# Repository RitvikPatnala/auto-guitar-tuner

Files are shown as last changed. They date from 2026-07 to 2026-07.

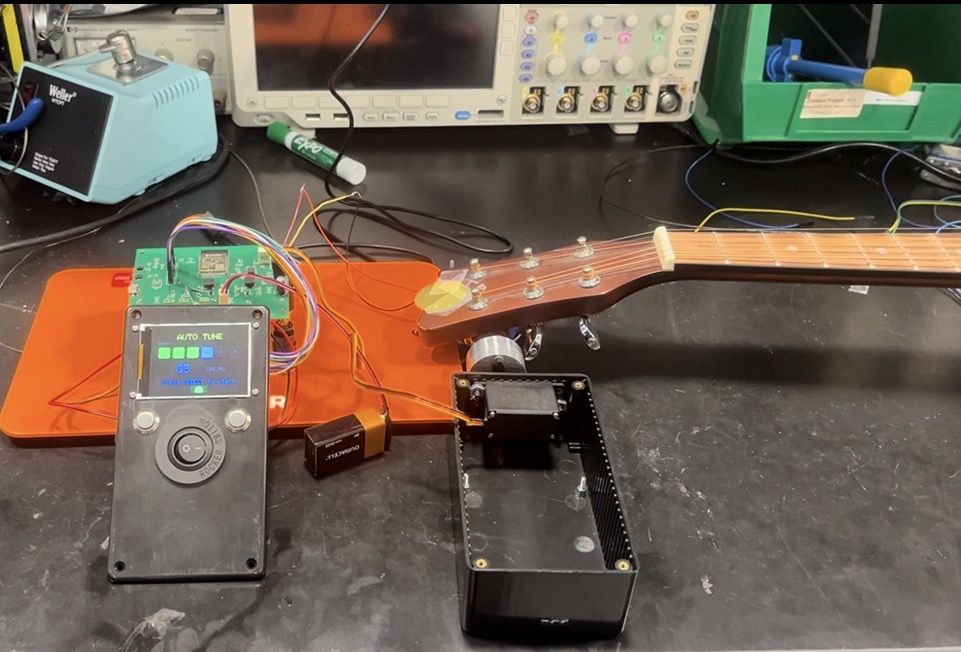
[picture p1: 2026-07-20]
docs/Guitar Tuner Demo.jpg

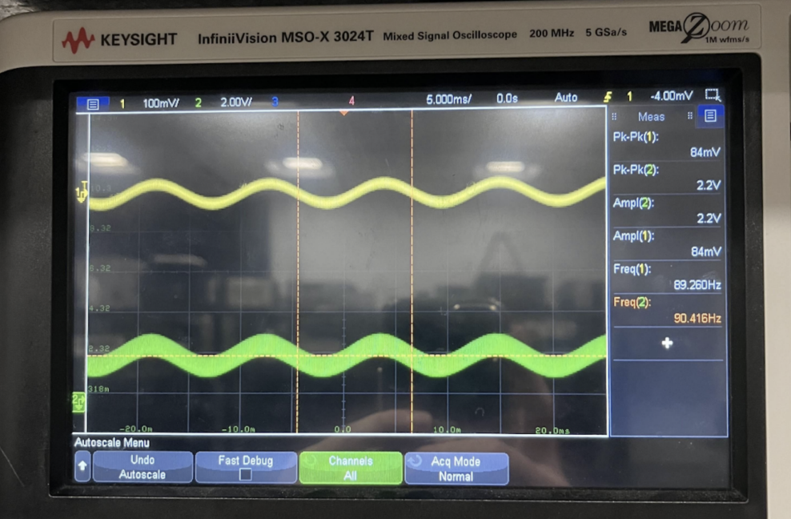
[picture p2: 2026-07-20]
docs/Amplified Output.png

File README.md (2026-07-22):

# Auto Guitar Tuner

A handheld device that detects a guitar string's pitch and physically rotates the tuning peg until the string is in tune. Built around a custom ESP32-S3 PCB designed from schematic capture to routed layout, with real-time pitch detection firmware and closed-loop servo control. Tunes to within ±12 cents across all six strings and multiple tuning standards (Standard, Eb, Drop D, Open G).

Screenshot 2026-07-20 at 3 30 26 PM

## How it works?

1. A piezo vibration sensor mounted on the guitar picks up string vibrations (immune to ambient room noise, unlike a microphone).
2. An LM386 amplifier stage (gain ≈ 50) with a 1.6 kHz RC anti-aliasing filter conditions the signal for the ESP32-S3's ADC (8192 Hz, 12-bit).
3. Firmware detects the fundamental frequency using time-domain autocorrelation and computes the error from the target pitch in cents.
4. A PID controller drives an HS-318 servo attached to the tuning peg, making small angular corrections until the string is in tune — with safety interlocks (rotation limits, stall           detection, voicing threshold) to protect the guitar.
5. A TFT LCD (SPI) and two-button interface let the user select strings and tuning modes via an FSM-driven UI.

## Why Autocorrelation instaead of FFT?

The most interesting design decision in the project. Guitar strings produce strong harmonics — the 2nd harmonic often carries more energy than the fundamental, so naive FFT peak-picking frequently reports the octave above the true pitch. Time-domain autocorrelation measures the signal's self-similarity across lag values, which naturally locks onto the fundamental period. It was also faster on the ESP32-S3:

| Approach | Latency |
|---|---|
| Autocorrelation | ~22 ms |
| FFT + peak detection | ~48 ms |

The pipeline: Hann window → autocorrelation over the guitar's lag range (73–330 Hz) → normalization → zero-crossing peak detection → parabolic sub-sample interpolation for resolution beyond the lag grid. The ~22 ms loop lets the tuner track pitch continuously while the motor turns, so the user doesn't need to re-pluck after every adjustment.

## Hardware Design

- Power: dual AP62150 buck converters (9V battery → 5V and 3.3V rails). Chosen over LDOs after a dissipation analysis — a stalled servo draws 800 mA, which would burn 3.2 W in an LDO vs ~90% buck efficiency.
- Custom PCB: designed in KiCAD (schematic → layout), simulated in LTSpice; noise mitigated with ground partitioning, supply decoupling, and the RC input filter.

Screenshot 2026-07-21 at 8 55 34 PM

Screenshot 2026-07-21 at 8 56 06 PM

- Motor: HS-318 analog servo, selected over a stepper for closed-loop position feedback and full torque at low speed. Torque analysis: 0.25 kg·cm required at the peg vs 3.7 kg·cm available.

## Verification Highlights

| Subsystem | Result |
|---|---|
| Power rails | 3.353 V / 4.995 V measured (±1% of nominal) |
| Audio chain | Gain of ~52 measured (target 50); piezo signal 84 mV |
| Pitch detection | ±12 cents final tuning accuracy, ~22 ms latency |
| Control | Autonomous tuning verified on all 6 strings + alternate tunings |

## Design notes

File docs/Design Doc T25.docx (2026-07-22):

# Outline

Tim Ritvik Daniel

1. Introduction
  - Problem and Solution: Reuse, edit original One to two paragraphs explaining the context of the problem to be solved by your project, including any relevant references to justify the existence and/or importance of the problem (i.e., the need or want for a solution). Justify the novelty of your solution or explain the expected improvements of your solution over previous results.
  - Visual Aid A pictorial representation of your project that puts your solution in context. Not necessarily restricted to your design. Include other external systems relevant to your project (e.g. if your solution connects to a phone via Bluetooth, draw a dotted line between your device and the phone). Note that this is not a block diagram and should explain how the solution is used, not a breakdown of inner components.
  - High-level requirements list: Rework Original A list of three to four objective characteristics that this project must exhibit in order to solve the problem. These should be selected such that if any of these requirements were not met, the project would fail to solve the problem. Avoid vague requirements that can be interpreted a number of ways (e.g. "The radio subsystem should work reliably."). Each high-level requirement must be stated in complete sentences and displayed as a bulleted list.
2. Design
  - Block Diagram: Mostly done, maybe needs rework? A general block diagram of the design of your solution. Each block should be as modular as possible and represent a subsystem of your design. In other words, they can be implemented independently and re-assembled later. The block diagram should be accompanied by a brief (1 paragraph) description of the critical subsystems and what they do.
  - Physical Design (if applicable): A physical diagram of the project indicating things such as mechanical dimensions or placement of sensors and actuators. The physical diagram should also be accompanied by a brief one paragraph description.
  - [Subsystem X] All subsystems needs requirements and verification For each subsystem in your block diagram, you should include a highly detailed and quantitative block description. Each description must include a statement indicating how the block contributes to the overall design dictated by the high-level requirements. Any and all design decisions must be clearly justified. Any interfaces with other blocks must be defined clearly and quantitatively. Include any relevant supporting figures and data in order to clearly illustrate and justify the design. Typically a well justified block design will include some or all of the following items: Circuit schematics, simulations, calculations, measurements, flow charts, mechanical diagrams (e.g. CAD drawings, only necessary for mechanical components). You must include a Requirements and Verifications table. Please see the R&V page (https://courses.grainger.illinois.edu/ece445/guidelines/requirements-and-verification.asp) for guidance on writing requirements and verification procedures.
  - Motor Subsystem ...
  - Audio Subsystem
  - Power Subsystem
  - Microcontroller Subsystem
  - USB-C Subsystem
  - LCD Subsystem ...
  - Tolerance Analysis: Through discussions with your TA, identify the block or interface critical to the success of your project that poses the most challenging requirement. Analyze it mathematically and show that it can be feasibly implemented and meet its requirements. See the Tolerance Analysis guide (https://courses.grainger.illinois.edu/ece445/documents/tolerance-analysis-guide.pdf) for further guidance.
  - Include any relevant supporting figures and data in order to clearly illustrate and justify the design. Typically a well justified block design will include some or all of the following items: Circuit schematics, simulations, calculations, measurements, flow charts, mechanical diagrams (e.g. CAD drawings, only necessary for mechanical components). You must include a Requirements and Verifications table. Please see the R&V page (https://courses.grainger.illinois.edu/ece445/guidelines/requirements-and-verification.asp) for guidance on writing requirements and verification procedures.
  - [Subsystem Y] ...
  - [Subsystem Z] ...
  - Tolerance Analysis: Through discussions with your TA, identify the block or interface critical to the success of your project that poses the most challenging requirement. Analyze it mathematically and show that it can be feasibly implemented and meet its requirements. See the Tolerance Analysis guide (https://courses.grainger.illinois.edu/ece445/documents/tolerance-analysis-guide.pdf) for further guidance.
3. Cost and Schedule
  - Cost Analysis: Include a cost analysis of the project by following the outline below. Include a list of any non-standard parts, lab equipment, shop services, etc., which will be needed with an estimated cost for each.
    i. Labor: (For each partner in the project) Assume a reasonable salary ($/hour) x 2.5 x hours to complete = TOTAL Then total labor for all partners. It's a good idea to do some research into what a graduate from ECE at Illinois might typically make.
    ii. Parts: Include a table listing all parts (description, manufacturer, part #, quantity and cost) and quoted machine shop labor hours that will be needed to complete the project.
    iii. Sum of costs into a grand total
  - Schedule: Include a time-table showing when each step in the expected sequence of design and construction work will be completed (general, by week), and how the tasks will be shared between the team members. (i.e. Select architecture, Design this, Design that, Buy parts, Assemble this, Assemble that, Prepare mock-up, Integrate prototype, Refine prototype, Test integrated system).
4. Discussion of Ethics and Safety:
  - Expand upon the ethical and safety issues raised in your proposal to ensure they are comprehensive. Add any ethical and safety concerns that arose since your proposal.
  - Document procedures to mitigate the safety concerns of your project. For example, include a lab safety document for batteries, human/animal interfaces, aerial devices, high-power, chemicals, etc. Justify that your design decisions sufficiently protect both users and developers from unsafe conditions caused by your project. Projects dealing with flying vehicles, high voltage, or other high risk factors, will be required to produce a Safety Manual and demonstrate compliance with the safety manual at the time of demo.
5. Citations:  Any material obtained from websites, books, journal articles, or other sources not originally generated by the project team must be appropriately attributed with properly cited sources in a standardized style such as IEEE, ACM, APA, or MLA.

# Design Doc

# Auto-Guitar Tuner Design Document

Daniel Cho, Ritvik Patnala, Timothy Park
Team 25 - TA: Eric Tang

Abstract

This document provides a comprehensive description of the Auto-Guitar Tuner, a handheld device that automates guitar tuning by integrating pitch detection, microcontroller-based control, and motorized peg adjustment. It outlines the system architecture, physical and functional designs, subsystem requirements and verifications, software flow, tolerance analyses, cost considerations, and safety protocols. The tuner is designed to operate as a standalone portable device compatible with standard six-string guitars.

1. Introduction 4

1.1 - Problem and Solution 4

1.2 - Visual Aid 4

1.3 - High-level requirements list 4

2. Design 5

2.1 - Block Diagram 5

2.2 - Physical Design 6

2.3 - Subsystems 7

2.4 - Tolerance Analysis 21

3. Cost and Schedule 22

3.1 - Cost Analysis 22

3.2 - Schedule 24

4. Discussion of Ethics and Safety 26

6. Citations 30

# 1. Introduction

## 1.1 - Problem and Solution

Problem: When playing guitar, being in tune is essential. When strings are not properly tuned to their correct pitches, the notes played can clash with each other, causing what listeners perceive as being "off" or "out of tune." Accurately tuning a guitar is a challenge for both beginners and experienced players. Traditional tuners require the musician to manually turn tuning pegs while reading pitch information, which can be inconsistent and time-consuming. An automatic solution that can both detect pitch and physically adjust the tuning peg would reduce errors, speed up tuning, and improve usability in practice and performance settings.

Solution: We propose a handheld automatic guitar tuner integrating pitch detection and motorized peg adjustment into one device. The system will capture string vibrations, process them using a microcontroller to identify the current pitch, and automatically rotate the tuning peg with a small motor until the string is in tune. Since the handheld device tunes one string at a time, it can be used on different guitars without worrying about the various spacing between pegs and strings. A compact LED screen will display the detected pitch and tuning status, while four buttons (Power, String Select, Mode, Start) provide simple user control. The String Select button allows users to cycle through the six guitar strings. Each press moves the selection to the next string in order: low E, A, D, G, B, high E, then back to low E again. This circular navigation lets users easily choose which string to tune without confusion or the need for multiple buttons. The Mode button lets users toggle between preset tuning standards (Standard, Drop D, Open G, etc) to accommodate various playing styles and preferences. The design will run on a rechargeable battery, with all subsystems integrated into a custom PCB for portability and reliability.

## 1.2 - Visual Aid

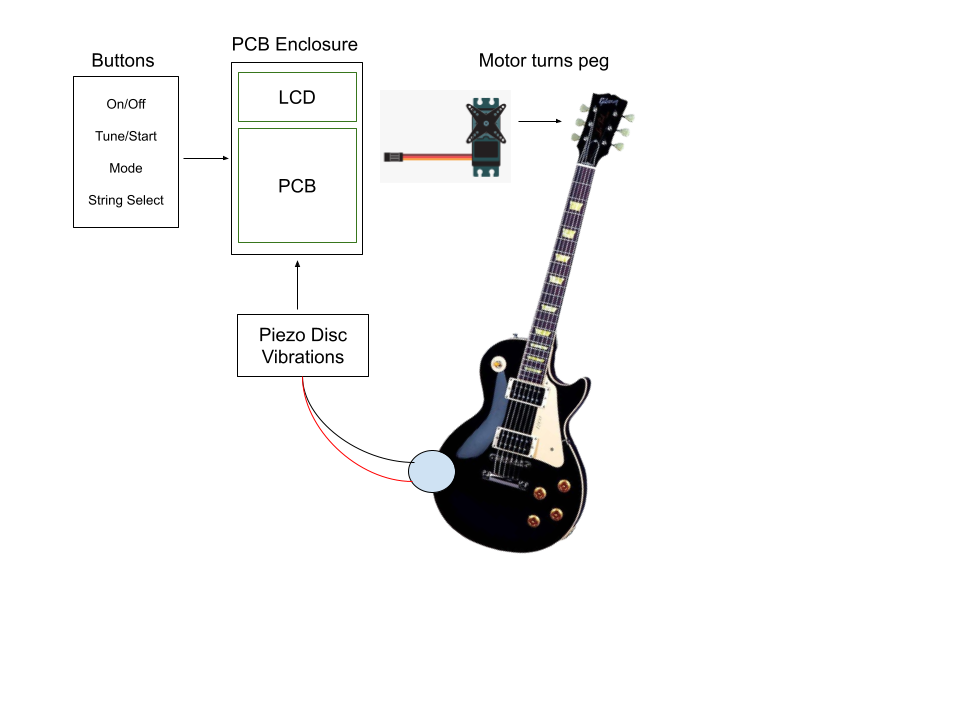
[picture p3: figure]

## 1.3 - High-level requirements list

# 2. Design

## 2.1 - Block Diagram

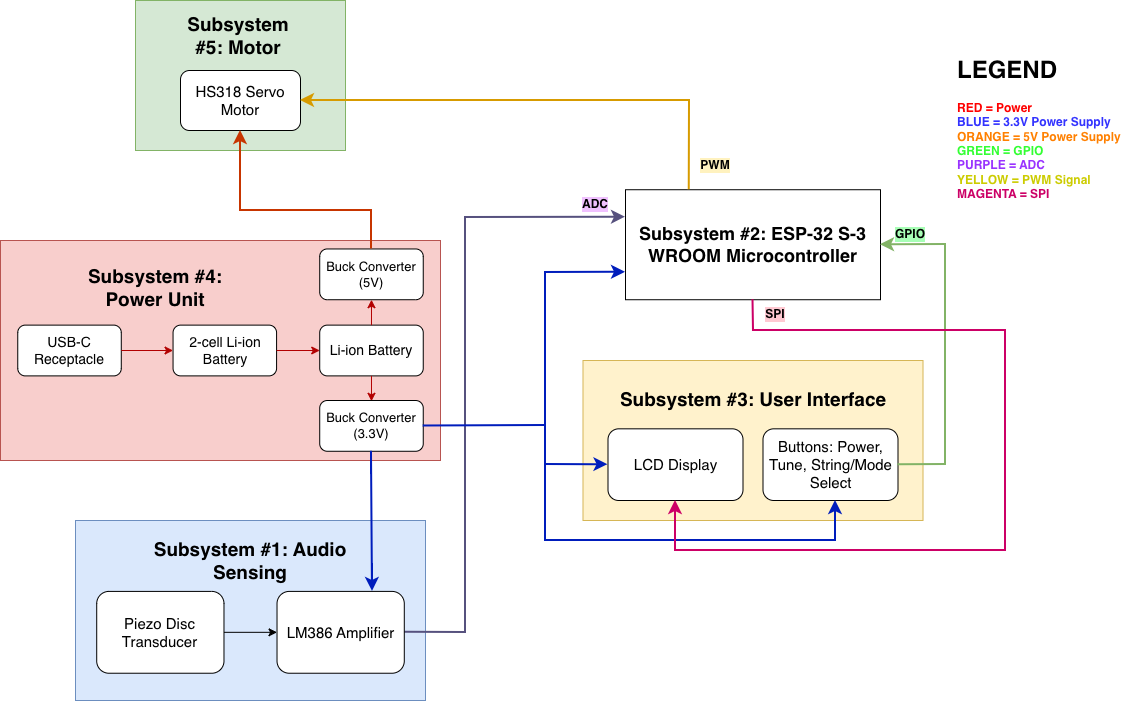
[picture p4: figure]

Figure 1. Image of the block diagram

The system consists of five main subsystems: Power Management, Microcontroller, Audio Sensing, User Interface, and Motor. The ESP32 microcontroller serves as the central unit, interfacing with all subsystems to coordinate power regulation, audio sampling, digital signal processing, motor control, and user interaction.

## 2.2 - Physical Design

The Auto-Guitar Tuner is contained in a small, portable, rectangular shell. Functionality, usability, and internal electronics protection are prioritized in the physical design. OpenSCAD was used to model and render the device's base and detachable lid in CAD. The enclosure is stable when placed close to the guitar headstock and is the right size to fit comfortably in the user's palm.

A 2.4-inch LCD display on the front panel shows the system status and tuning feedback in real time. Four horizontally oriented tactile control buttons for power, string selection, mode switching, and tuning initiation are located beneath the display. During operation, this arrangement enables rapid access with little hand movement. On the side is a micro-USB connection for data transfer and charging.

The motor output shaft and a fork-style coupler that fits normal guitar tuning pegs are located in the top panel. In order to enable the motor to rotate the peg during automated tuning, this coupler firmly grasps the tuning key. To manage torque without jeopardizing the enclosure's structural integrity, the motor boss is reinforced.

Lastly, to ensure that the components are properly aligned with the external features, the design incorporates mounting bosses for the PCB and battery on the inside.

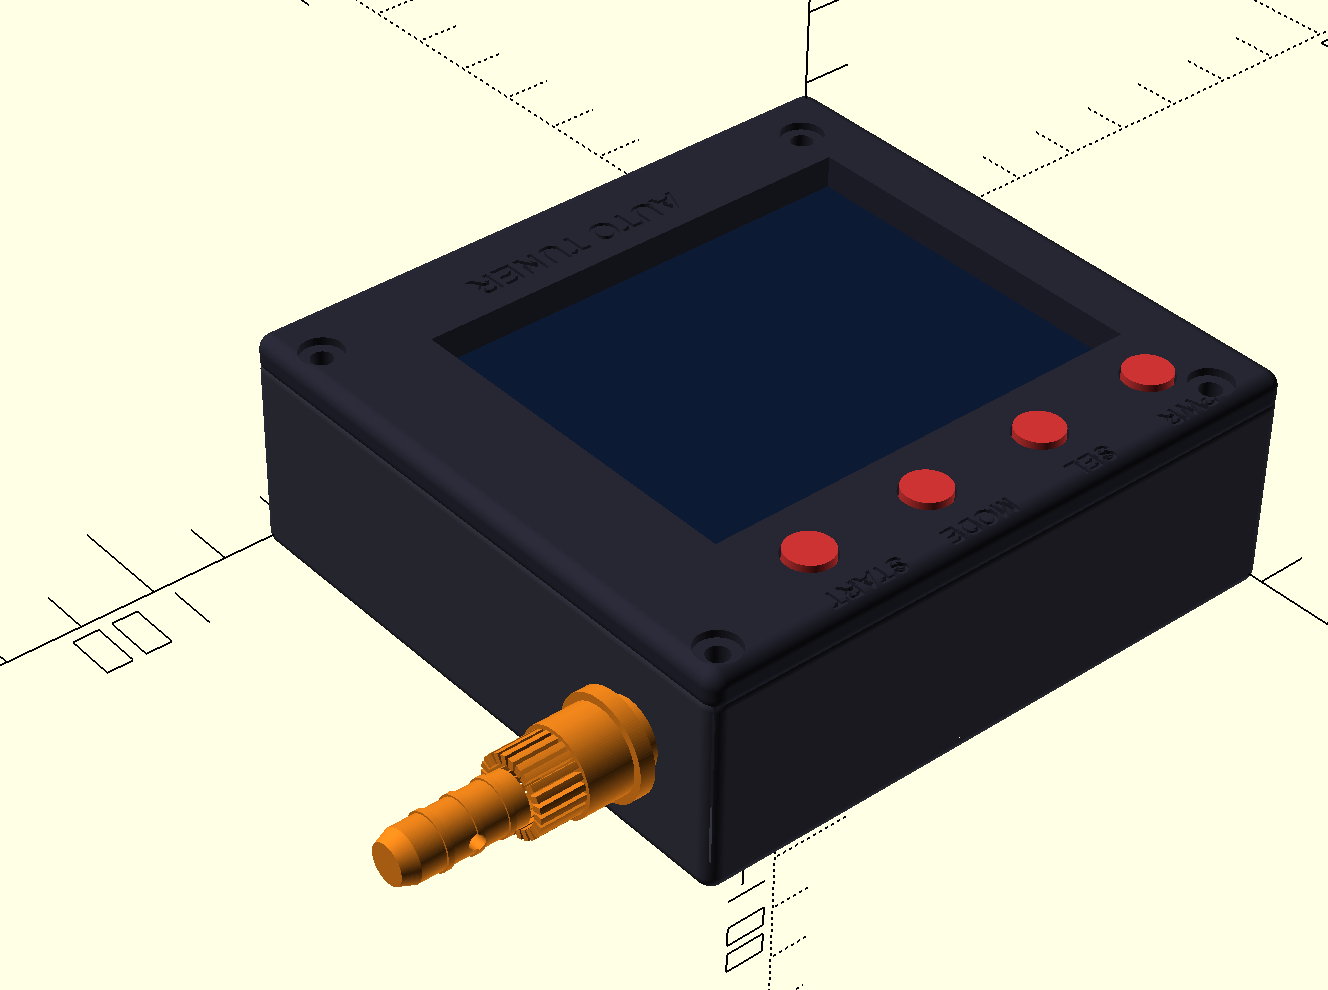
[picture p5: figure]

Figure X. Isometric rendering of the enclosure, highlighting the display, buttons, and turning peg adapter on the motor shaft

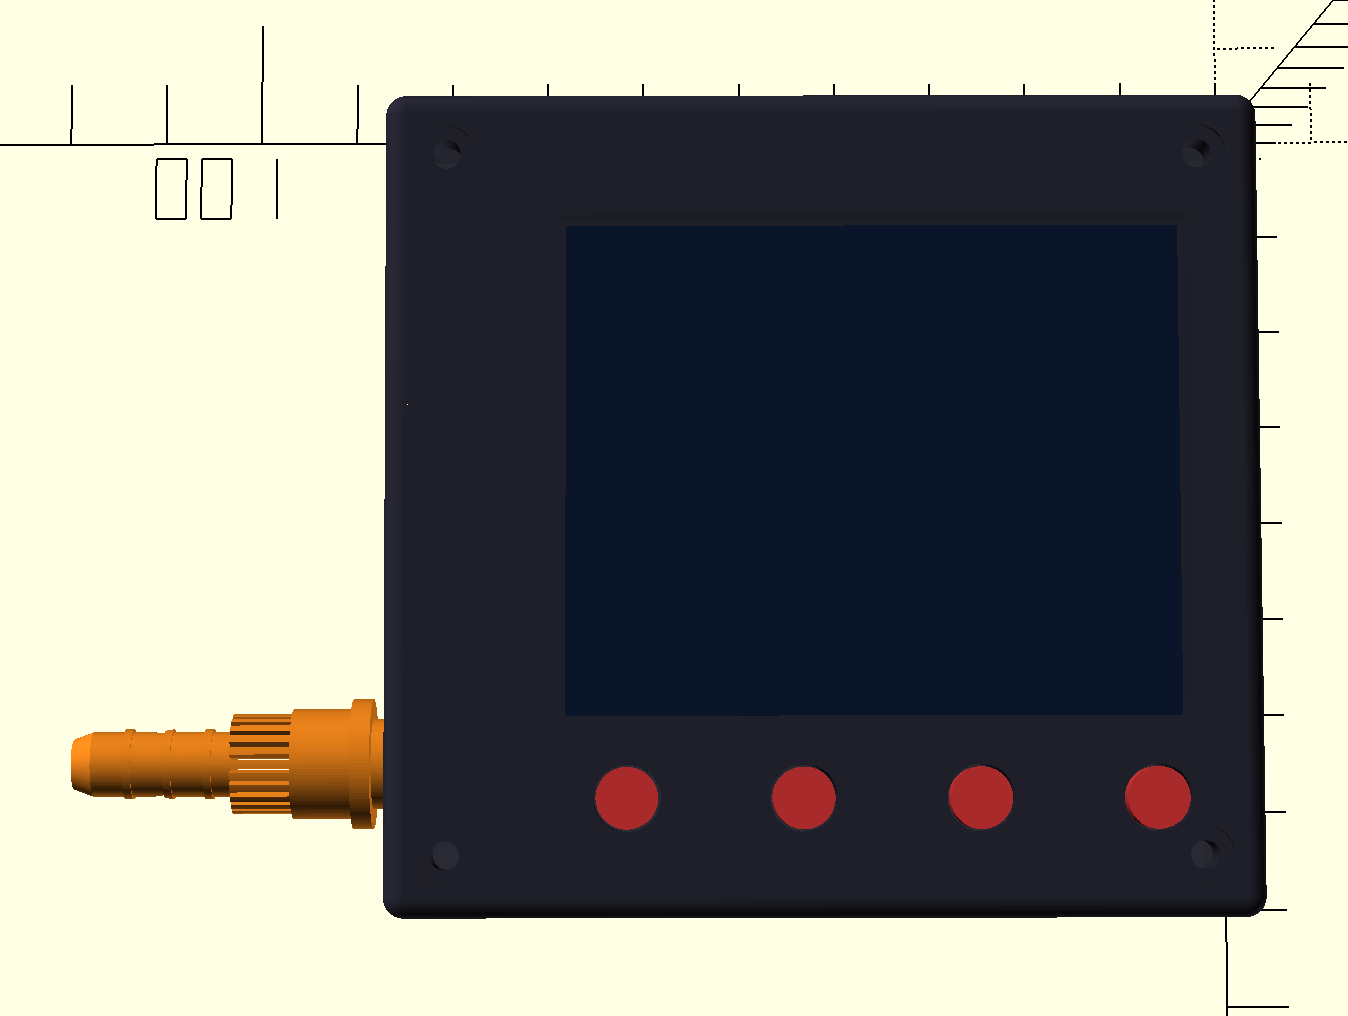
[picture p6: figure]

Figure X. Top view rendering of the Auto-Guitar Tuner showcasing the button and the display’s layout.

## 2.3 - Subsystems

2.3.1 Power Management Subsystem

The power management subsystem is responsible for controlling the power delivery to all other subsystems of the PCB. For our first few rounds of PCBs, we’re planning to convert a 9V signal (from a 9V battery) to 5V and 3.3V using two different AP62150WU-7 Buck Switching Regulators. One of the big reasons we chose to use this specific buck switching regulator, is because it has up to 1.5A of continuous output current. Although we’re planning to use the same IC for both power rails, we are using various resistor values to adjust the voltage drops and produce the stable 5V and 3.3V rails for our subsystems. The motor, micro USB-B receptacle, and the amplifier IC all require 5V. Meanwhile, the ESP32, the LCD screen and the amplifier IC require 3.3V.

Since this subsystem produces stable DC voltage lines, we don’t need to use the built-in voltage converter in the ESP32, and simply use the power management subsystem to safely deliver power to the rest of the system. Our component values for the resistor, capacitors, and inductors were selected using the recommended values from the datasheet [2] shown in the table figure below.

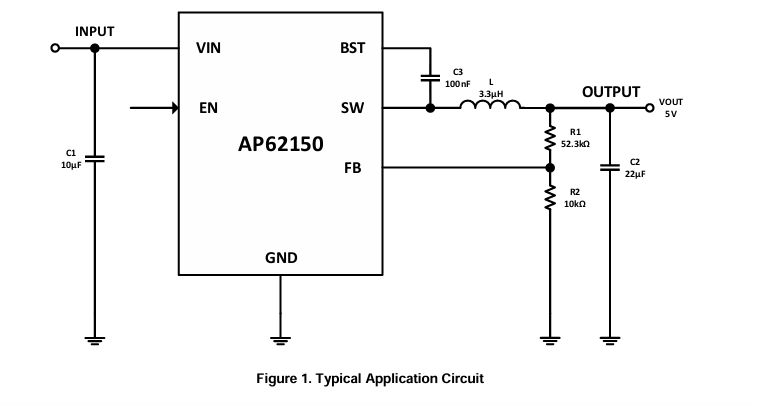
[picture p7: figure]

Figure X. Sample Application Circuit taken from the AP62150 datasheet [2]

Figure X. Table displaying recommended component values to achieve desired output voltage.

Schematic:

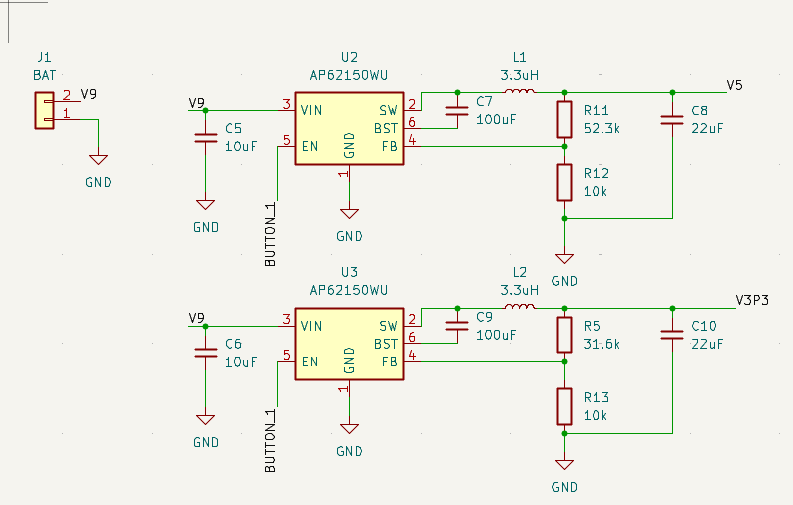
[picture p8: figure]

Requirements and Verifications

Requirement | Verification
Stable 3.3V line with tolerance of 5% (3.135-3.465V) | Measure 3.3V line using oscilloscope
Stable 5V line with tolerance of 5% (4.75-5.25V) | Measure 5V line using oscilloscope
Maintain ±2-3% of nominal output voltage during a fast load step | Use an oscilloscope to measure both output voltage lines, and verify that it remains within 2-3% during a fast load step.
Continuous, stable 5V line within ±5% when servo motor stalls | Monitor the 5V rail with an oscilloscope, and intentionally stall the motor.

2.3.2 Control Subsystem

The control subsystem is essentially the microcontroller. For this project, we chose the ESP-32 S-3 WROOM microcontroller. The purpose of the microcontroller is to first process the audio signal received from the audio subsystem (vibration sensor and amplifier). This implies determining the pitch frequency of the audio signal. The next step is to compare the measured pitch frequency and desired frequency, and translate the difference to PWM commands for the servo motor to rotate the tuning peg. Apart from this, it should also be able to send data using the SPI interface to the display to showcase the string, pitch frequency, how far off the measured pitch frequency is to the desired frequency, and the status of the tuner. The inputs that it takes in are the string select and mode select.

Specifications:

Memory | 384KB ROM, 512KB SRAM
Peripherals | 36 GPIOs, SPI, LCD Interface, UART
Operating Voltage | 3.0V - 3.6V
Features | 32-bit LX7 microprocessor

We chose this particular chip since it has a much higher computation power and comes with an SPI flash and 40MHz crystal to program the ESP-32 chip. Apart from this, it also supports all the necessary interfaces including SPI, GPIOs, and UART. We also had a potential idea to leverage the WiFi and bluetooth features of this microcontroller by having the microphone or vibration sensor much closer to the sound hole of the guitar and send data over bluetooth. [8]

Figure X. ESP-32 S-3 WROOM Chip

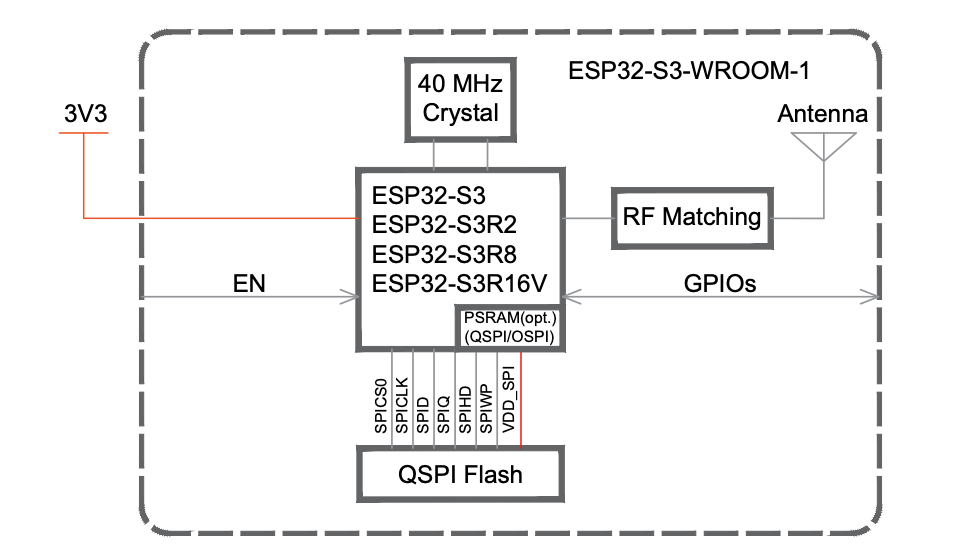
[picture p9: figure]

Control Unit:

(i) Inputs:

There are 3 primary inputs that the ESP-32 needs to process. The first 2 are buttons that choose the string and tuning standard/mode. These buttons are debounced and connected to the GPIO pins of the microcontroller. We plan on using polling to constantly read the pin. Based on the tuning standard and the string chosen to be tuned, a pitch frequency is already preset. The last input required is the audio signal from the audio subsystem.

(ii) Processing:

The audio signal from the vibration subsystem is connected to the ADC pin of the ESP32. It is sampled at 4096 Hz for 20 ms frames. A hanning window is applied to reduce spectral leakage.

Figure X. Hanning Window

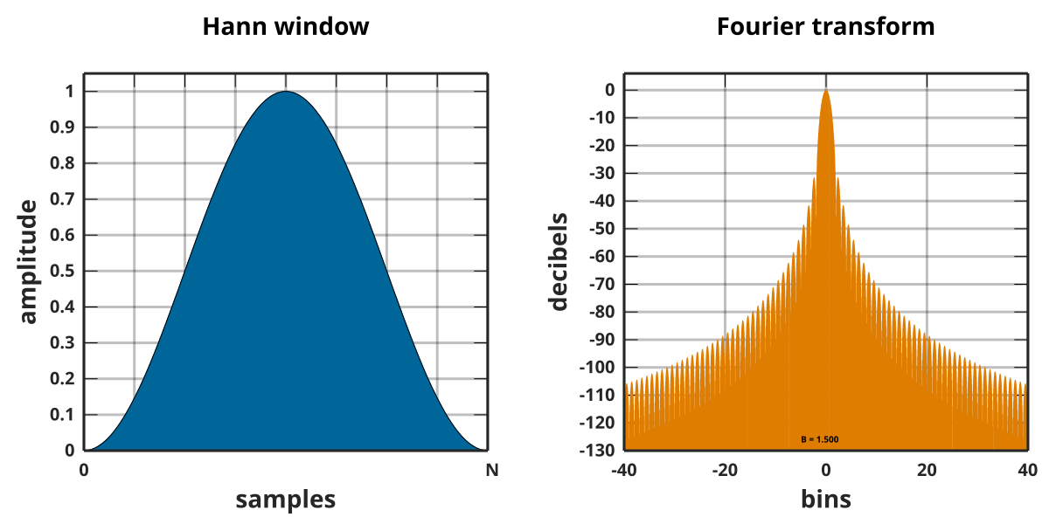
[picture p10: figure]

The pitch detection algorithm will use autocorrelation. Autocorrelation is the correlation of a signal with itself on different delays.

R_(xx) [k]=∑_n x[n]x[n+k]

Rxx = Autocorrelation Function; x[n] = Sampled Audio Signal, k = Lag

The maximum is at lag l=0 [9]. Rxx can also be calculated in the frequency domain by multiplying the FFT of the audio signal with its conjugate and computing the inverse FFT of the entire signal.

R_(xx) [k]=IFFT(FFT(x[n])×FFT^(*) (x[n]))

This autocorrelation function is then normalized to ρ_(xx) [k] .

ρ_(xx) [k]=(R_(xx) [k])/(R_(xx) [0])

This normalized autocorrelation function then goes through zero crossing. This is essentially to see how similar the function is to the time-shifted version of itself by k samples. This value of k that leads to the autocorrelation function to be most similar with the time-shifted versions is the lag that we use to compute the pitch frequency.

Pitch Frequency=(Fs)/k

Fs = Sampling Rate; k = Lag

Once the pitch frequency is detected using the method above, it needs to be compared to the desired frequency of the string in that particular tuning standard. We plan on using a Proportional Integral Derivative (PID) controller to achieve this. A PID controller is an instrument that receives input data, calculates the difference between the actual value and the desired point, and adjusts the output to control variables, in our case, the motor. [10]

The first step is to determine the difference between the set point (desired frequency) and the measured process variable (measured pitch frequency).

e[k]=1200log_2 ((f_0)/(f_(tgt)))

e[k] = Difference; f0 = Actual Pitch Frequency; ftgt = Desired Frequency

The output u[k] is given by: Output=Proportional+Integral+Derivative

u[k]=KPe[k]+KI∫_0^k e[k]dk+KD(de[k])/(dk)

KP, KI and KD = constants based on the PID Controller

U[k] is then used to compute the number of degrees that the motor must be rotated to tune the string. [11]

(iii) Output:

There are 2 primary outputs from the microcontroller. As mentioned earlier, the output of the PID controller can be used to determine the number of degrees to rotate the motor. This output is sent in the form of a pulse width modulation signal from a GPIO pin to the servo motor. See section 2.3.5 for more on this.

The next output is to the display. The display showcases the string being tuned at the moment, the frequency, and how far off the current frequency is to the desired frequency. The data is sent to the display using the SPI interface. Other pins on the display such as the chip select, clock, reset and backlight are all connected to GPIO pins on the ESP32.

Figure X. LCD Display

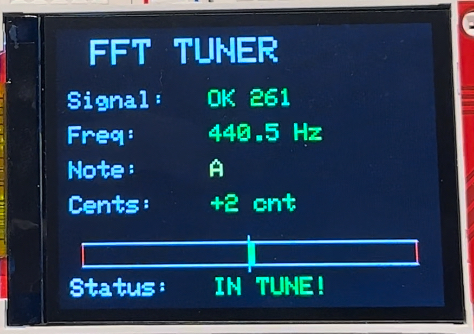
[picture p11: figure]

Programming:

In order to program the ESP32, we have to set up a USB Receptacle. We chose to use the USB 2.0 Micro B receptacle. The receptacle uses a differential pair for signal integrity in order to program it. The D+ and D- pins need to be connected to the USB_D+ and USB_D- of the microcontroller. [12]

Figure X. Control Subsystem Circuit Diagram

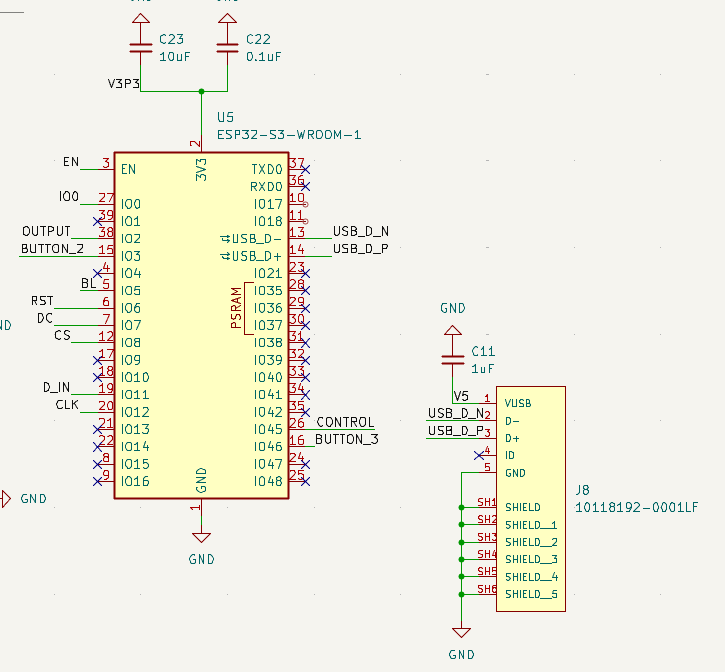
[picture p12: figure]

Requirements and Verification:

Requirements | Verification
Pitch to Rotation: ESP32 shall detect the string’s fundamental frequency and compute the required tuner rotation to reach the target pitch. | A function generator can be used to replicate the strumming of the string. An oscilloscope can be used to look at the PWM signal coming out of it to see if it is the correct amount of rotation.
LCD Status &UX: ESP32 shall render real-time status to the LCD without disrupting sensing and control. | Run tuning cycles to see if the display showcases the correct string, how far off the pitch is, and when the guitar string is in tune.
Safety Interlocks: Block motor commands when unvoiced/noisy frame or overcurrent and stall occurs. | Trigger each safety condition (unvoiced frame, overcurrent, stall) and on a scope, timestamp the fault event edge, the PWM disable edge, and the LCD fault flag. If the PWM is off for approximately 100ms and the LCD display shows the fault within 100ms of the fault.

2.3.3 Audio/Vibration Subsystem

The vibration subsystem is responsible for recognizing the current pitch of a guitar string. We plan to use a piezo disc sensor, and place it onto the guitar so it can pick up the mechanical vibrations generated when a string is plucked. To amplify the piezo signal, we’re using the LM386-MX1 amplifier. This amplifier seems to be perfect for this application since it is meant for low-voltage applications, and the signal generated from the piezo will be in the 100-500mV RMS range.

At the vout pin, we’ve connected the output in between two 10kΩ resistors, so that the 3.3V gets cut and the signal centeres around ~1.65V. This is to ensure the signal will fit within the 0-3.3V range for the ESP32 ADC input and maximizes the frequency resolution. From there, we designed a low pass filter with the R9 (10kΩ) resistor and C12 (0.01uF) capacitor to attenuate the higher frequencies.

Using the formula: f_c =1/(2πRC)=1/(2π*10000*0.01*10^(-6))=~1591Hz .

This filter has a cutoff frequency around 1591Hz, which is perfect for our application. The highest fretted note on the guitar (24th fret, E-string) is ~1318Hz, which is within this range. But since we will be tuning with open strings, the open E string should have a frequency of around 329Hz. Both of these frequency points are less than 1591Hz, so this filter will be good for eliminating noise and some higher partial harmonics.

The C19 (0.1uF Capacitor) will be used to stabilize the VS voltage used to power the amplifier, and the C1 (0.1uF Capacitor) will be used to eliminate any DC offset from the piezo signal, and only allow the AC signal to pass through into the amplifier. The 1MΩ resistor is used to provide high impedance at the input, to make sure the full piezo signal can be captured and carried into the amplifier.

Both the gain pins (pins 1 and 8) are left unconnected in our schematic since the default gain value for this amplifier is 20 (26 dB).

Schematic:

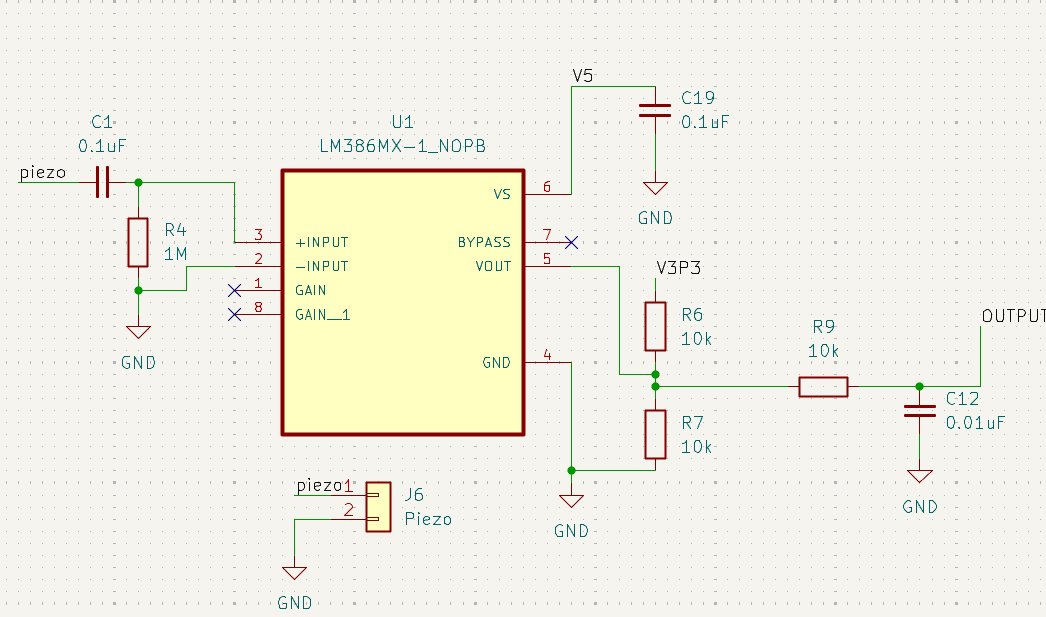
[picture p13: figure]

Requirement | Verification
Piezo input signal ≥ 10mV | Measure the voltage across the two piezo disc wires to ensure signal measures above 10mV.
Output signal amplitude must be 20x as large as the piezo input amplitude | Measure the amplitude of the input piezo signal as well as the output of the LM386 amplifier using an oscilloscope under the same conditions
Current drawn from the power supply pin should be less than 4mA. | Insert a multimeter to measure current between the 5V rail and the V5 pin.

2.3.4 User Interface Subsystem

Purpose and Overview

Throughout the tuning process, the User Interface (UI) subsystem controls all user interactions and offers visible feedback in real time. Four tactile buttons (Power, String Select, Mode, and Start) plus a small OLED display coupled to the ESP32 microcontroller via SPI make up the interface. Users can choose target strings, set up tuning modes, start tuning operations, manage device power, and monitor system status with this subsystem's clear visual feedback. Rapid, distraction-free tuning is made possible by the design's emphasis on straightforward operation, which includes few controls and clear feedback.

Hardware Components

OLED Display

- Operating voltage: 3.3V
- Interface: SPI
- Operating current: ~30mA
- Display content: Current string selection, target frequency, measured frequency, tuning error

Control buttons

- Type: 4x momentary switches
- Connection: ESP21 GPIO pins with internal pull-up resistors
- Logic: Active-low
- Debouncing: Software-based

UI State Machine

The subsystem manages the display and the user input by utilizing a Finite State Machine (FSM) as follows.

State | Description | Transition
Boot | Initialize GPIO, SPI peripherals, and display | → Ready (after system initialization)
Ready | Display current string and mode selection; await user input | → Tuning (Start button pressed) → Standby (timeout) → Fault (system error)
Tuning | Show real-time frequency, error magnitude (cents), and motor direction | → Success (in-tune condition met) → Aborted (Start button pressed) → Fault (system error)
Success | Display “In Tune” confirmation | → Ready (after 2s or button press)
Aborted | Show cancellation message | → Ready (after 1s)
Fault | Display error message (motor stall, input clipping, low battery) | → Ready (after acknowledgement)

Figure X. Table depicting the states and their transitions of the UI Finite State Machine.

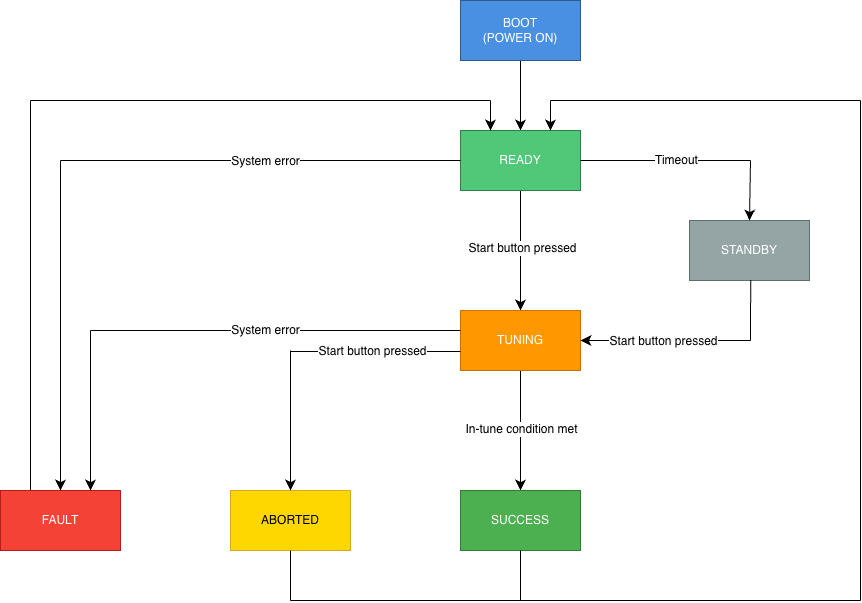
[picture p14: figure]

Figure X. Diagram depicting the logic flow of the UI Finite State Machine (FSM)

Button Functions

Through a combination of short and long push operations, the four control buttons offer full user interaction capabilities. Long presses necessitate holding the button for more than 1.5 seconds, and short presses are defined as any button activation lasting less than 1.5 seconds. This dual-purpose method preserves intuitive functioning while reducing the amount of physical controls.

The Power button only reacts to lengthy presses to turn the device's power on or off; it lacks a short-press capability. Unintentional power cycling during regular use is avoided thanks to this thoughtful design decision.

With each brief click of the String Select button, the six standard guitar strings are cycled through in ascending sequence (E2 → A2 → D3 → G3 → B3 → E4), returning to E2 after E4. Users can swiftly move backward through the string sequence without continuously cycling forward by long-pressing this button, which reverses the cycle direction.

Standard tuning, drop D, and open G are among the tuning modes that can be selected by short pushes on the Mode button. When navigating between modes that are not contiguous, a long press reveals a separate mode selection menu that shows every mode that is available at once for direct selection.

Depending on the status of the system, the Start button's functionality varies depending on the situation. A quick press starts the tuning process when the device is in the Ready state. Pressing Start again while active tuning instantly ends the process and puts the device back in Ready mode. Long presses from any state bring up a help overlay with basic usage instructions and button functionalities; this overlay automatically disappears after a few seconds or when a button is touched.

Button | Short Press | Long Press (> 1.5s)
Power (Toggle button aka switch) | – | Toggle device power
String Select | Cycle forward (E2 → A2 → D3 → G3 → B3 → E4 → E2) | Cycle backward
Mode | Cycle through tuning modes | Open mode selection menu
Start | Begin / Stop tuning | Display help overlay

Figure X. Table depicting the operations of the 4 momentary switches.

Requirements and Verifications

Requirement | Verification Method
Button press must be registered within 200ms | Measure response with a logic analyzer
OLED must display the updated string selection | Cycle through strings and verify the display
Mode switching must change target frequencies | Toggle modes and verify the displayed reference
Display must refresh without flickering | Observe the continuous tuning display during operation

2.3.5 Motor Subsystem

The motor subsystem is responsible for rotating the tuning pegs on the guitar. This subsystem consists of the servo motor (HS318) and is controlled by sending an electrical pulse of variable width or pulse width modulation (PWM). This motor is made up of a small DC motor, a potentiometer, and a control circuit. Gears are attached to the control wheel. As the motor starts to rotate, the potentiometer’s resistance changes so the control circuit can precisely regulate how much movement there is to be done and in which direction. The potentiometer essentially provides live feedback about the shaft’s angle. The control circuit compares where the shaft is (potentiometer reading) and where it should be (PWM signal). The difference tells whether the motor should rotate in one direction or the other, and when to slow down and stop at the target angle. [1]

Operating Voltage (Volts DC) | 4.8V - 6.0V
Max Torque Range (kg cm) | 3.0-3.7
Current Draw at Idle/No-Load/Stall (mA) | 8/180/800
Circuit Type | Analog
Physical Specifications | Standard 25 Output Shaft; Plastic Casing; Cored Metal Brush, Nylon Gear
Range of Motion | 180°

Design Choice:

Our initial choice was to use a stepper motor over a servo motor. The differences between the 2 motors are highlighted in the table below. [6]

| Stepper Motor | Servo Motor
Control Method | Moves in fixed steps | Uses potentiometer feedback
Torque | Torque drops at higher speeds | High torque across the range
Precision | Depends on the step size | Continuous position feedback allows for higher precision tuning
Flexibility | Cannot react to changes in load | Better choice for variable load systems

One of our high level requirements is for the tuner to be able to get the desired pitch within 12 cents. For such high precision, a stepper motor isn’t ideal without the feedback loop of the servo motor. Moreover, different strings have different tensions and therefore loads making it difficult to work with a stepper motor.

Figure X. Motor Subsystem Circuit Diagram (Connector)

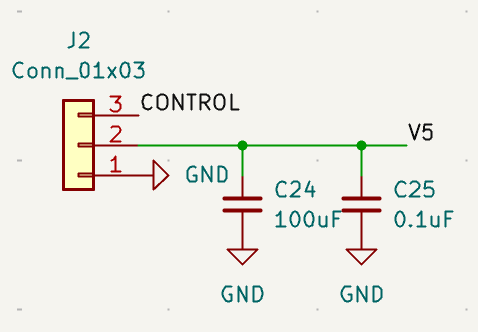
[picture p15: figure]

The circuit diagram above showcases how we are connecting the servo motor to the PCB and the ESP-32 microcontroller. The control signal is essentially the PWM signal that the motor will receive from a GPIO pin on the microcontroller. The ceramic capacitor is placed closer to the servo’s power pins to filter out high-frequency noise and voltage spikes that could be caused by nearby digital circuitry and PWM motor switching. The electrolytic capacitor is used to store much more charge and respond to low frequency dips and surges in current draws. [5]

Servo Motor Control:

As mentioned, the PWM signal sent to the motor will determine the position of the shaft, and based on the duration of the pulse, the rotor will turn to the desired position. There are 3 parameters that characterize the waveform: pulse voltage, pulse width, and pulse period. The pulse voltage for the HS318 servo motor is approximately 3.3V to 5V. For the most part, the signal amplitude does not matter much, as long as it is high enough for the servo to register the pulses. The pulse width is what controls the motor. The servo motor expects a pulse every 20ms [4]. We can control how much the servo moves by setting a new pulse width that corresponds to the desired end position, using its internal potentiometer for feedback.

1.5ms | Neutral: HS318 servo motor has a neutral angle at 90°. This implies that the motor can move 90° in either direction.
< 1.5ms | Counter-Clockwise: The servo motor will move counter clockwise for pulse widths lesser than 1.5ms.
> 1.5ms | Clockwise: The servo motor will move in the clockwise for pulse widths greater than 1.5ms.

Figure X. Servo Motor Pulse Width to Rotation Diagram

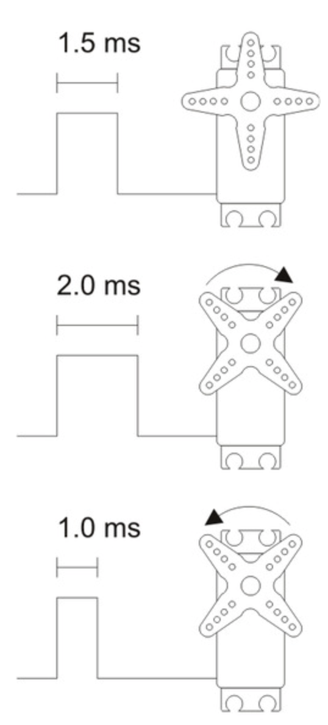
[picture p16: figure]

Based on the specifications of the HS318 servo motor, the maximum available torque to us is 3.7 kg cm. The first step is to determine the torque required at the string post. The tension of a string ranges from 60N - 80N, and the typical radius of a post is 3mm = 0.003m.

τ_(post) =T×r_(post) =80N×0.003m=0.24Nm

τ = Torque ; T = Tension of String; rpost = Radius of the string post

Our motor is going to be connected to the tuner knob/tuning peg. Hence, the torque required from the motor to rotate this knob is given by the formula below:

τ_(motor) =(τ_(post))/(raio×η)=(0.24Nm)/(14×0.7)=0.0245Nm=0.25kg⋅cm

η = efficiency

Most guitar tuning machines use a worm and gear mechanism, so when we rotate the knob, the post turns more slowly. The ratio of the peg to post is 14:1 for typical acoustic guitars. The Mechanical efficiency takes into account friction and other forces that may affect the tuning and is typically 0.7.

Based on these calculations, the torque required from the motor is 0.25 kg cm, which is much lesser than the maximum available torque for the motor (3.7 kg cm).

Requirements and Verifications

Requirement | Verification Method
Angular Resolution: Servo motor should be able to rotate the tuning peg with an accuracy of 1°, which translates to approximately 5-7 cents on an acoustic guitar. | Command smaller movements to random angles and measure the actual movement using an external reference such as a shaft encoder.
PWM Command: the servo motor should be able to receive the correct PWM based on the difference between the current and desired frequency. | Measure the PWM signal using an oscilloscope at the control pin of the servo motor or GPIO pin of the microcontroller. The pulse width should mathematically translate to the necessary rotation.
Motor Position: Servo motor should rotate to the desired position (±1°). | Once the motor rotates to the position it was commanded to, the microcontroller should register that the string is in tune when it is strummed again. No further rotations should be seen as well. Console/Display should show that the string is in tune.

## 2.4 - Tolerance Analysis

One of our biggest concerns for our project is the vibration system. Being able to accurately capture the current guitar string’s pitch is the single most crucial aspect of our system, since it affects how the motor turns the peg so that the motor can make the correct adjustments to the tuning pegs. Our piezo sensor detects mechanical vibrations through the body of the guitar and converts the mechanical energy into an electric signal that can be processed by the microcontroller. This approach is more feasible compared to using a microphone, since we won’t have to worry about ambient noise or other loud environments.

However, the piezo sensors we’re using (B0B2QS8VK5 35mm piezo disc) have material and manufacturing tolerances. The resonance frequency is specified around 3-5 kHz ±0.5 kHz. Luckily, the guitar string frequencies we are interested in are in the range from a low D2 (73Hz) to a high E4 (330 Hz). Since the resonance frequency sits far above the target frequencies we desire, the frequencies we desire below this range can be connected with linearity. So we know our piezo sensors will be able to capture all the notes we need.

One of the key reasons we chose to use the LM386MX-1 amplifier IC is that it has adjustable gain values. This way, if a specific piezo sensor has a varying sensitivity, we can adjust the gain so that we won’t have to rework our whole vibration amplification system. For now, we’re planning to use a gain of 20, but we might plan to change the gain value if we need to compensate for changes in mounting strategy or part tolerances.

# 3. Cost and Schedule

## 3.1 - Cost Analysis

Parts Cost:

Component | Part Number | Manufacturer | Vendor | Quantity | Price | Use
ESP32 Microcontroller | ESP32-S3-WROOM-1-N16R8 | Espressif Systems | Digikey | 1 | $6.56 | Breadboard (we chose before designing the PCB, but used for the 1st breadboard demo)
ESP32-S3 DevBoard | ESP32-S3-DevKitC-1-N32R16V | Espressif Systems | Amazon | 1 | $17.00 | Use for breadboard demo 2, more prototyping
Mic Amplifier | MAX9814 | Adafruit | Amazon | 3 | $9.99 | For initial breadboard, before switching to piezo
35 mm Piezo Disc Transducer | B0B2QS8VK5 | YQBOOM | Amazon | 10 | $9.99 | PCB
2.4inch LCD Display Module | B08H24H7KX | Waveshare | Amazon | 1 | $18.99 | PCB
2.2inch LCD breakout board | B01CZL6QIQ | HiLetgo | Amazon | 1 | $14.49 | Initially used for Breaboard demo 1 and prototyping basic UI
Buck Switching Regulator IC | AP62150WU-7 | Diodes Incorporated | Digikey | 2 | $0.66 ($0.33 each) | PCB
USB - micro B USB 2.0 Receptacle Connector | 10118192-0001LF | Amphenol ICC | Digikey | 1 | $0.43 | PCB
Amplifier IC | LM386MX-1 | Texas Instruments | Digikey | 1 | $0.85 | PCB
Tactile Switch | KMR232NG ULC LFS | C&K | Digikey | 2 | $1.40 ($0.70 each) | PCB
100uF Electrolytic Capacitor | 35ZLH100MEFC6.3X11 | Rubycon | Digikey | 1 | $0.32 | PCB
3.3uH Fixed Inductor | VLS6045EX-3R3N | TDK Corporation | Digikey | 2 | $0.68 ($0.34 each) | PCB
31.6kΩ Resistor | ERA-6AEB3162V | Panasonic Electronic Components | Digikey | 1 | $0.10 | PCB
52.3kΩ Resistor | ERA-6AEB5232V | Panasonic Electric Components | Digikey | 1 | $0.10 | PCB
| | | | Total: | $81.56

Labor Costs:

According to the [7] Grainger Engineering career services salary and hiring data portal, the average graduate makes $96,270 a year. Assuming approximately 2080 hours a work week, that is approximately $46.28 per hour. Since this is a 16-week course, and we can expect about an average of 15 hours a week, the labor cost is $46.28 * 16 weeks * 15 hours = $11,107.20. And since our group has 3 team members, 11107.20 * 3 members = $33,321.60

Total Costs: $33.321.60 (labor costs) + $81.56 (parts cost) = $33,403.16

## 3.2 - Schedule

Week | Goals | Assigned
9/29 | -Pick components, verify parts can handle power and current levels -Design PCB -Get feedback at the PCB review -Prototype motor and basic pitch processing on the ESP Dev-board | -Tim and Ritvik -Tim and Ritvik -All -Daniel
10/6 | -Finalize PCB -Finalize working motor and microphone for breadboard demo 1 -Layout, routing -Breadboard demo 1 | -Tim and Ritvik -Tim and Ritvik -Daniel -All
10/13 | -Finish Design Doc -Evaluate Teamwork -Submit parts order -Talk to Greg to finalize machine shop order for PCB casing -Begin working/prototyping on UI for LCD display -Second Round PCB order | -All -All -Tim -Ritvik -Daniel -All
10/20 | -Prototype audio/vibration subsystem -Prototype UI subsystem on LCD module -Test different standard tuning modes to make sure pitch is properly recognized -Verify amplifier circuit on breadboard | -Daniel -Daniel -All -Tim and Ritvik
10/27 | -Finalize microcontroller I/O and programming to make sure algorithms work and data is handled properly -Breadboard demo 2 -Review subsystem results and discuss changes to the PCB | -Daniel -All -All
11/03 | -Submit third wave PCB order (if needed) -Individual progress report -Begin assembling PCB -Test PCB | -Daniel -All -Tim -Ritvik
11/10 | -Test PCB -Unit test all subsystems | -Daniel -Tim
11/17 | -Final assembly and testing -Test and verify subsystem requirements -Accomplish all 3 high-level requirements -Mock demo | -All -All -All -All
11/24 | Fall Break
12/01 | -Edits, final changes / bug fixes -Final Demo -Begin preparing for the final presentation -Start write-ups for final report | -All -All -All -All
12/08 | -Submit final papers -Give Final Presentation -Make final updates to individual lab notebooks | -All -All -All

# 4. Discussion of Ethics and Safety

The IEEE and ACM Codes of Ethics, which place a strong emphasis on putting the public's welfare first, guaranteeing safety, being truthful about capabilities, and accepting responsibility for the results of design choices, are followed in the creation of the Auto-Guitar Tuner. Our objective is to create a device that is both morally and technically sound.

Ethical Considerations

Transparency and Honesty

We fully explain the tuner's performance features, such as its single-string operation, estimated battery runtime, and tuning precision of ±12 cents. In our lab reports, we will record all testing findings, including failures, and refrain from inflating performance.

Accessibility and Fairness

The UI is designed with readable fonts, intuitive layouts, and clear audio cues so that it can be used by beginners and experienced players alike. Simple controls and immediate feedback make the tuner accessible without requiring prior technical knowledge.

Intellectual Property and Environmental Impact

For components like the servo motor, we exclusively use publicly available datasheets and appropriately referenced open-source libraries (e.g. Arduino FFT). No proprietary designs or code are utilized without authorization. The tuner minimizes waste from disposable batteries by utilizing a rechargeable Li-ion battery. When feasible, components are chosen from reliable vendors who comply with RoHS.

Safety Considerations

The motor subsystem, which directly transfers torque to tuning pegs, is the main focus of the tuner's mechanical safety. Several safeguards are in place because excessive torque could harm the pegs or strings. By controlling the PWM duty cycle, the firmware limits motor torque and keeps it below levels that could damage the instrument. The motor reduces the possibility of overshooting the intended pitch by operating in tiny, gradual steps between frequency measurements. Firmware-imposed rotation constraints stop the peg from turning past safe limits in a single tuning operation, and a slip coupler acts as a passive mechanical safety measure by disengaging under excessive force.

In terms of electrical safety, the gadget makes use of a Li-ion battery that has built-in overcurrent and overdischarge protection as well as a certified charger integrated circuit. Both a fuse and a TVS diode protect against short circuits and reversed connections, and the USB-C charging input has ESD protection. The interior wiring is completely insulated and sealed to reduce the possibility of electrical shock or user contact, and all circuits run at a safe low voltage of 3.3 V.

Because the firmware directly controls the motor, software safety is essential. If the firmware hangs, uncontrollable behavior is prevented by tweaking timeouts and watchdog timers. Only after stable pitch detection does the motor actuate; if the signal is loud or unstable, the motor stays inactive. The system instantly stops working and notifies the user of an error if it detects a low battery, ADC saturation, or motor stall.

Lastly, explicit instructions for correct coupler installation, tuning, and charging are provided to ensure user safety. The user interface warns of abnormal conditions, including low battery, unstable pitch, or high mechanical resistance. The tuner is made for conventional six-string guitars. Together, these safeguards guarantee that the instrument and user can use the equipment securely.

5. Risk Analysis

If not handled correctly, the mechanical, electrical, and software parts of the auto-guitar tuner could endanger the player as well as the instrument. The main mechanical risk is that the tuning pegs, strings, or the tuner's coupler could be damaged if the motor applies too much torque to them. This risk is considerably decreased by a slip coupler, incremental motor adjustments, and firmware torque restrictions. The control logic's rotation limitations further guarantee that the motor never turns over safe limits in a single operation.

Li-ion batteries and power regulation circuitry are the primary electrical hazards. Damage or overheating may result from flaws such as reverse connections, short circuits, or overcharging. We incorporate a fuse and TVS diode, utilize a certified charger IC with current and thermal protection, and adhere to standard PCB design procedures for isolation and grounding to reduce these hazards. To reduce potential risks, all electronics run at low voltages.

The firmware's control over motor action is linked to software and control risks. The motor could spin constantly or in the wrong direction if the firmware hangs or misinterprets pitch signals. These situations are avoided via signal validation checks, tuning timeouts, and watchdog timers. The firmware stops the motor and shows a clear error message when there is any malfunction, such as motor stall, low battery, or ADC clipping.

The firmware's control over motor action is linked to software and control risks. The motor could spin constantly or in the wrong direction if the firmware hangs or misinterprets pitch signals. These situations are avoided via signal validation checks, tuning timeouts, and watchdog timers. The firmware stops the motor and shows a clear error message when there is any malfunction, such as motor stall, low battery, or ADC clipping.

Risk | Potential Consequence | Mitigation Strategy
Excessive motor torque | Damaged turning peg or string | Firmware torque limit, incremental steps, rotation bounds
Battery fault or short | Overheating, fire hazard, circuit damage | Certified charger IC, fuse, proper PCB layout
Firmware hang or incorrect control | Continous or unsafe motor rotation | Watchdog timer, timeouts, safe GPIO defaults
User misuse | Mechanical stress, poor tuning | Clear instructions, physical alignment features
Low battery during tuning | Brownout or device instability | Battery monitoring, lockout under critical voltage

Figure X. Table analyzing the potential risks of the Auto-Guitar Tuner.

# 6. Citations

[1] https://www.jameco.com/Jameco/workshop/Howitworks/how-servo-motors-work.html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

[2] https://www.diodes.com/assets/Datasheets/AP62150.pdf

[3] https://www.ti.com/lit/ds/symlink/lm386.pdf?HQS=dis-dk-null-digikeymode-dsf-pf-null-wwe&ts=1760376763005

[4]

https://www.pololu.com/blog/17/servo-control-interface-in-detail?utm_source=chatgpt.com

[5]

https://eepower.com/capacitor-guide/types/electrolytic-capacitor/#

[6]

https://eepower.com/capacitor-guide/types/electrolytic-capacitor/#

[7]

https://ecs.grainger.illinois.edu/salary-data/data-portal

[8]

https://www.espressif.com/sites/default/files/documentation/esp32-s3-wroom-1_wroom-1u_datasheet_en.pdf

[9]

https://scicoding.com/pitchdetection/

[10]

https://www.ni.com/en/shop/labview/pid-theory-explained.html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

[11]

https://apmonitor.com/pdc/index.php/Main/ProportionalIntegralDerivative

[12]

https://cdn.amphenol-cs.com/media/wysiwyg/files/documentation/datasheet/inputoutput/io_usb_micro.pdf

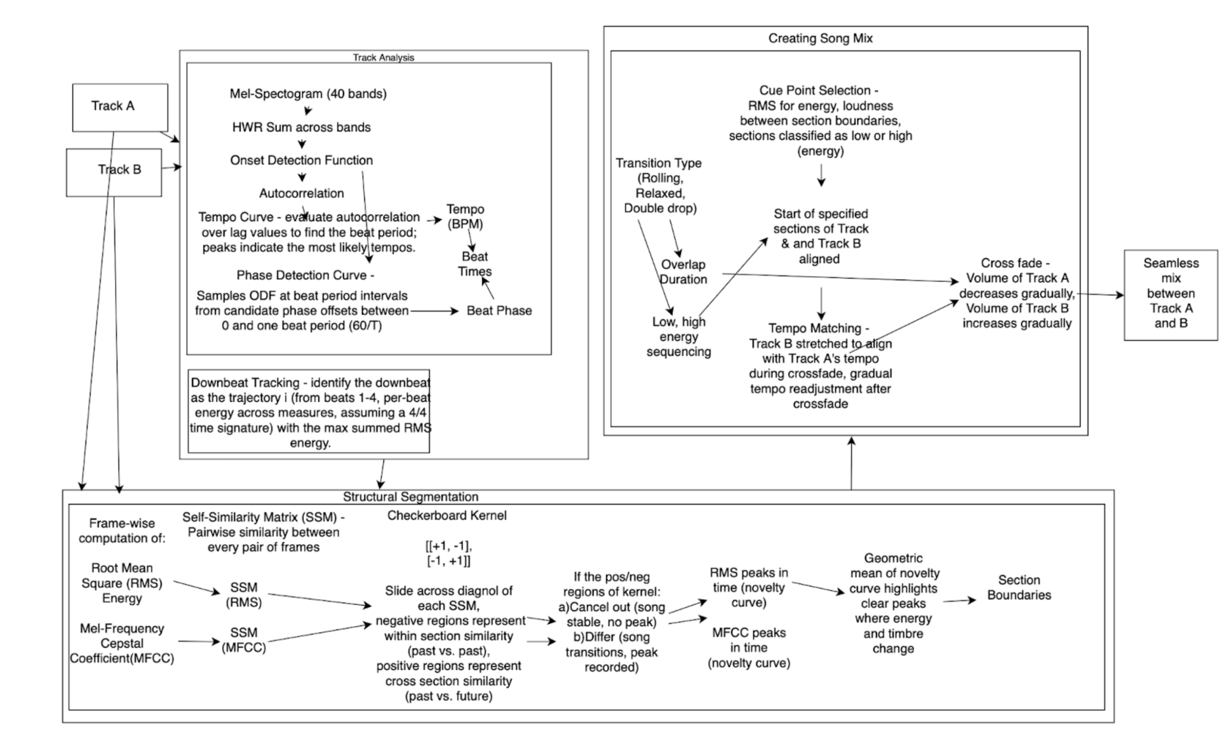
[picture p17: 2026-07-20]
docs/Block Diagram.png

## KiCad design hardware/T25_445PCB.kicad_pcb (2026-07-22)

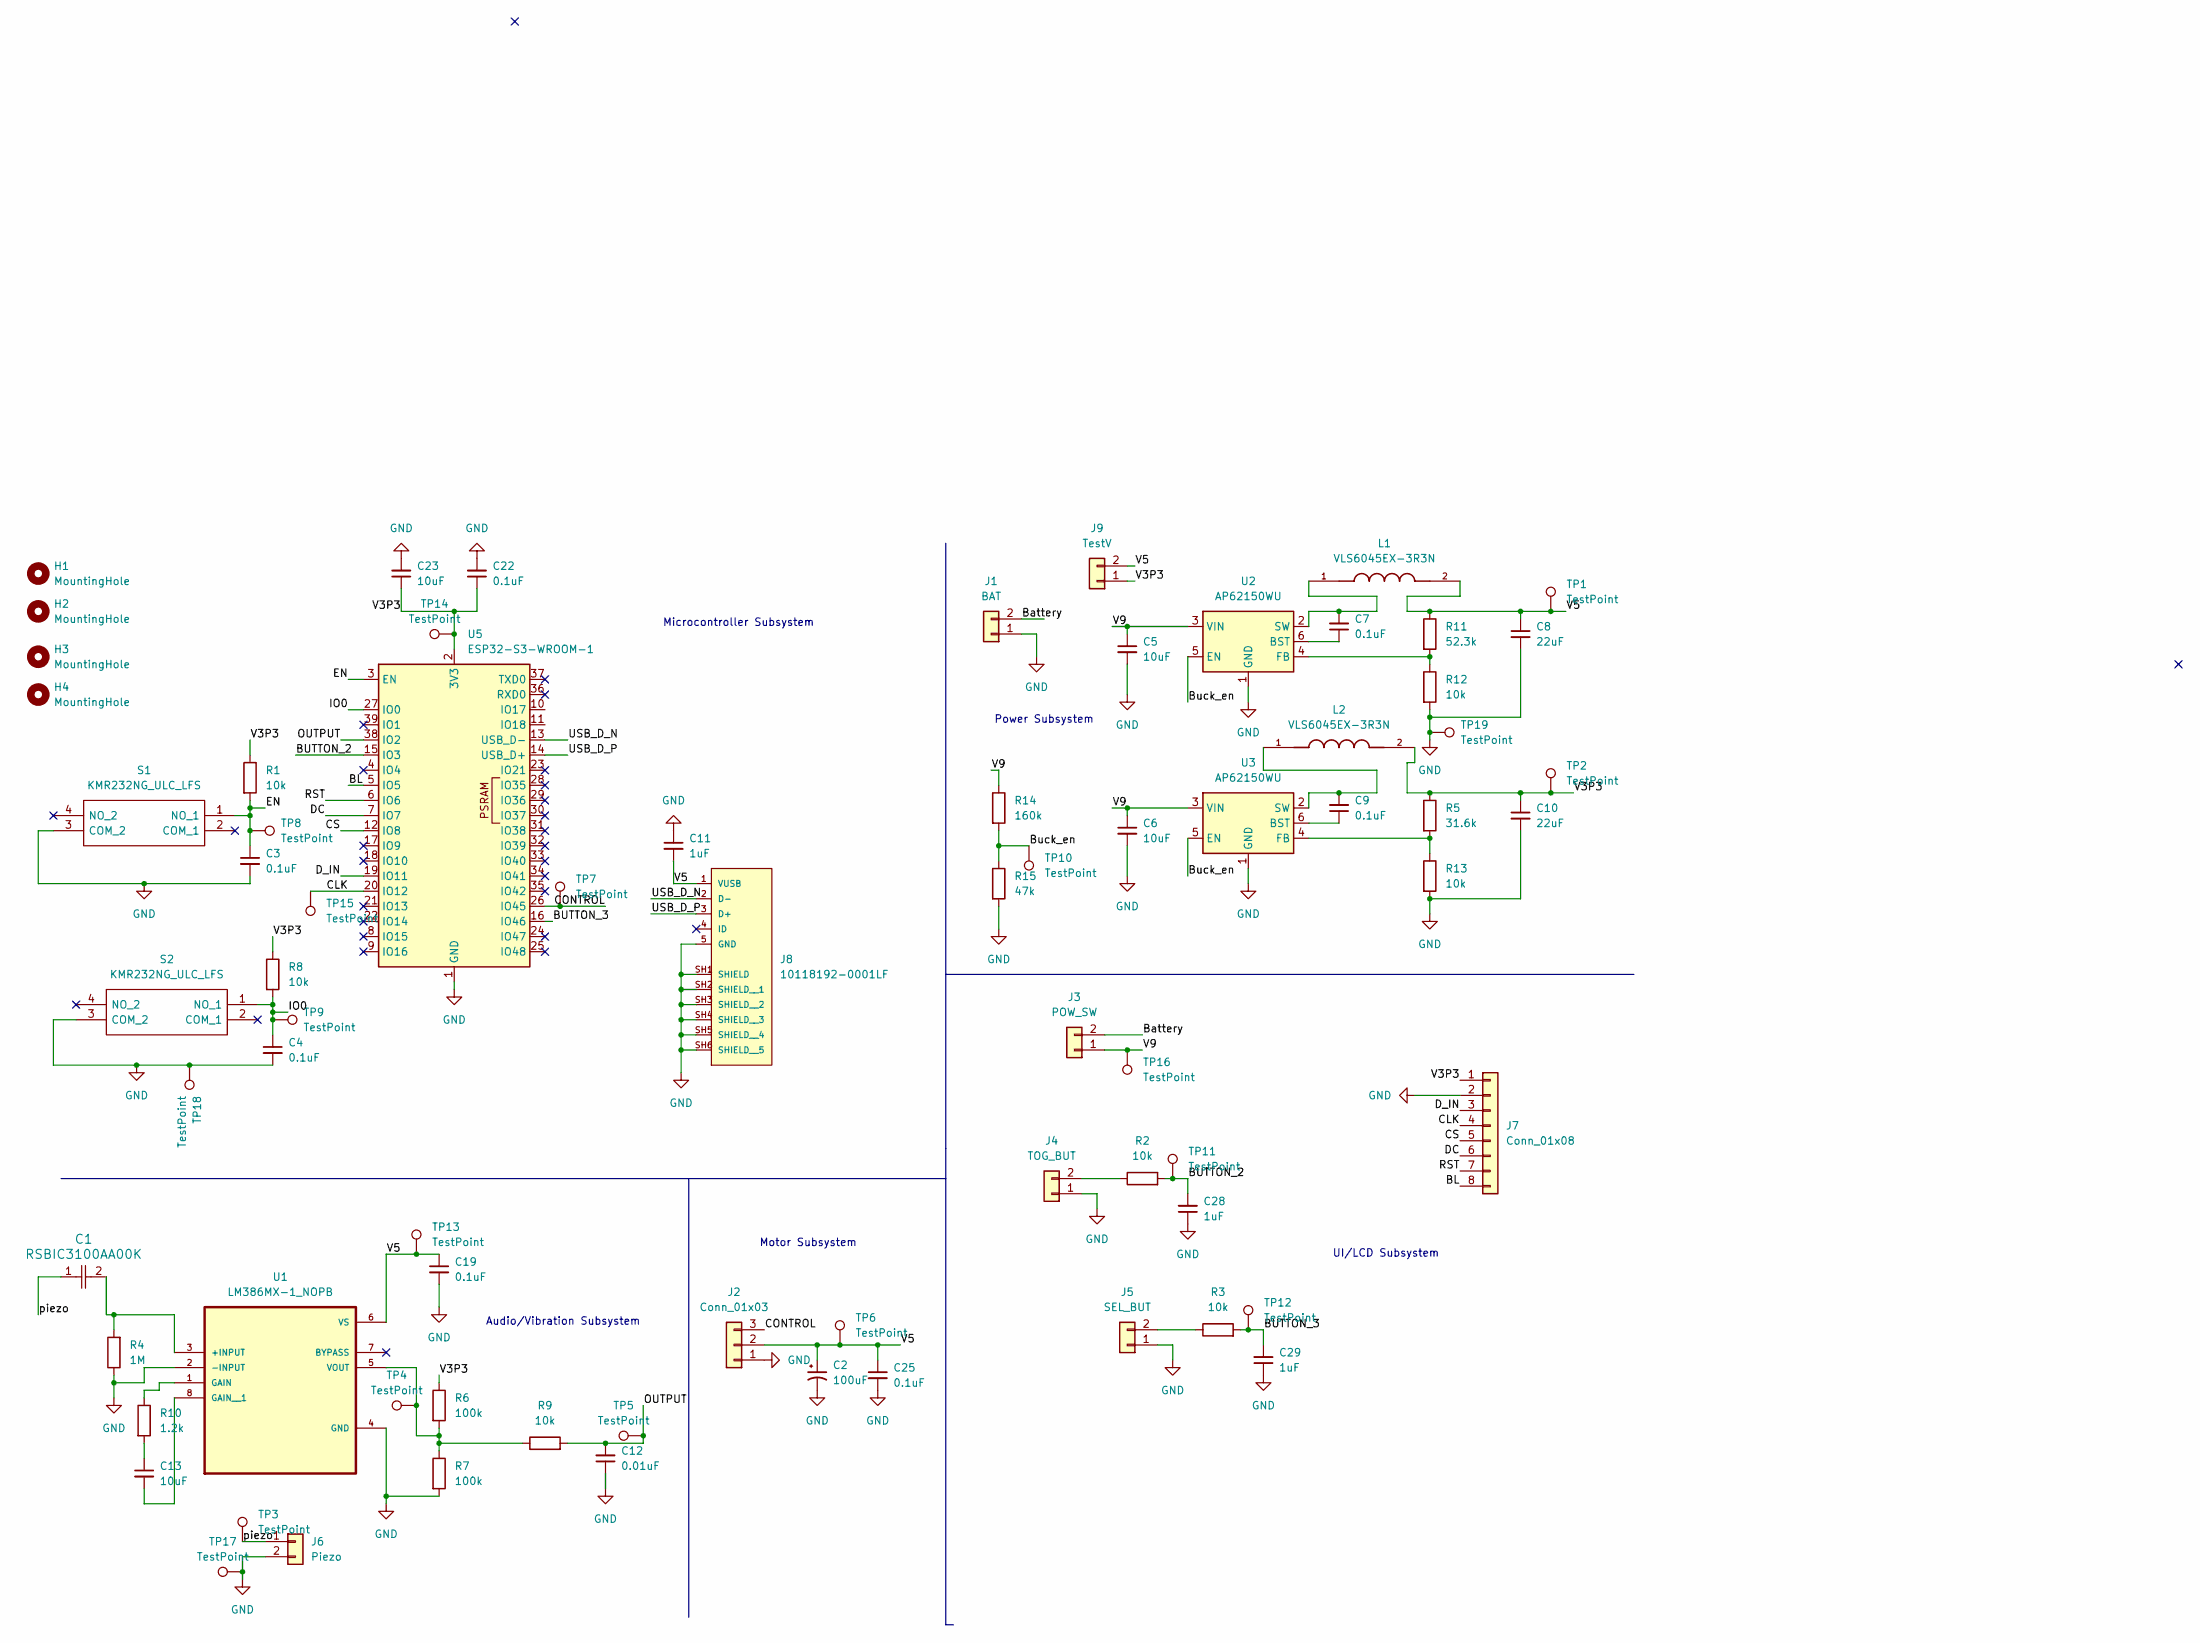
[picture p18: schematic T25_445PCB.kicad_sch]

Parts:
C1: RSBIC3100AA00K; CAP_RSBIC3100AA00K_KEM
C2: 100uF; CP_Radial_D6.3mm_P2.50mm
C3, C4, C7, C9, C19, C22, C25: 0.1uF; C_0805_2012Metric_Pad1.18x1.45mm_HandSolder
C5, C6, C13, C23: 10uF; C_0805_2012Metric_Pad1.18x1.45mm_HandSolder
C8, C10: 22uF; C_0805_2012Metric_Pad1.18x1.45mm_HandSolder
C11, C28, C29: 1uF; C_0805_2012Metric_Pad1.18x1.45mm_HandSolder
C12: 0.01uF; C_0805_2012Metric_Pad1.18x1.45mm_HandSolder
H1, H2, H3, H4: MountingHole; MountingHole_3.2mm_M3
J1: BAT; Molex_KK-254_AE-6410-02A_1x02_P2.54mm_Vertical
J2: Conn_01x03; Molex_KK-254_AE-6410-03A_1x03_P2.54mm_Vertical
J3: POW_SW; Molex_KK-254_AE-6410-02A_1x02_P2.54mm_Vertical
J4: TOG_BUT; Molex_KK-254_AE-6410-02A_1x02_P2.54mm_Vertical
J5: SEL_BUT; Molex_KK-254_AE-6410-02A_1x02_P2.54mm_Vertical
J6: Piezo; Molex_KK-254_AE-6410-02A_1x02_P2.54mm_Vertical
J7: Conn_01x08; Molex_KK-254_AE-6410-08A_1x08_P2.54mm_Vertical
J8: 10118192-0001LF; AMPHENOL_10118192-0001LF
J9: TestV; Molex_KK-254_AE-6410-02A_1x02_P2.54mm_Vertical
L1, L2: VLS6045EX-3R3N; IND_VLS6045EX-3R3N
R1, R2, R3, R8, R9, R12, R13: 10k; R_0805_2012Metric_Pad1.20x1.40mm_HandSolder
R4: 1M; R_0805_2012Metric_Pad1.20x1.40mm_HandSolder
R5: 31.6k; R_0805_2012Metric_Pad1.20x1.40mm_HandSolder
R6, R7: 100k; R_0805_2012Metric_Pad1.20x1.40mm_HandSolder
R10: 1.2k; R_0805_2012Metric_Pad1.20x1.40mm_HandSolder
R11: 52.3k; R_0805_2012Metric_Pad1.20x1.40mm_HandSolder
R14: 160k; R_0805_2012Metric_Pad1.20x1.40mm_HandSolder
R15: 47k; R_0805_2012Metric_Pad1.20x1.40mm_HandSolder
S1, S2: KMR232NG_ULC_LFS; KMR232NGULCLFS
TP1, TP2, TP6, TP13, TP14, TP16: TestPoint; TestPoint_Pad_D1.5mm
TP3, TP4, TP5, TP7, TP8, TP9, TP10, TP11, TP12, TP15: TestPoint; TestPoint_Pad_D1.0mm
TP17, TP18, TP19: TestPoint; TestPoint_Pad_D2.0mm
U1: LM386MX-1_NOPB; SOIC127P599X175-8N
U2, U3: AP62150WU; TSOT-23-6
U5: ESP32-S3-WROOM-1

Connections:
/BL: J7.8, U5.5 (IO5)
/BUTTON_2: C28.2, R2.2, TP11.1, U5.15 (IO3)
/BUTTON_3: C29.2, R3.2, TP12.1, U5.16 (IO46)
/Battery: J1.2, J3.2
/Buck_en: R14.2, R15.1, TP10.1, U2.5 (EN), U3.5 (EN)
/CLK: J7.4, TP15.1, U5.20 (IO12)
/CONTROL: J2.3, TP7.1, U5.26 (IO45)
/CS: J7.5, U5.12 (IO8)
/DC: J7.6, U5.7 (IO7)
/D_IN: J7.3, U5.19 (IO11)
/EN: C3.1, R1.2, S1.1 (NO_1), TP8.1, U5.3 (EN)
/IO0: C4.1, R8.2, S2.1 (NO_1), TP9.1, U5.27 (IO0)
/OUTPUT: C12.2, R9.2, TP5.1, U5.38 (IO2)
/RST: J7.7, U5.6 (IO6)
/USB_D_N: J8.2 (D-), U5.13 (USB_D-)
/USB_D_P: J8.3 (D+), U5.14 (USB_D+)
/V3P3: C10.1, C22.1, C23.1, J7.1, J9.1, L2.2, R1.1, R5.1, R6.1, R8.1, TP2.1, TP14.1, U5.2 (3V3)
/V5: C2.1, C8.1, C11.2, C19.1, C25.1, J2.2, J8.1 (VUSB), J9.2, L1.2, R11.1, TP1.1, TP6.1, TP13.1, U1.6 (VS)
/V9: C5.1, C6.1, J3.1, R14.1, TP16.1, U2.3 (VIN), U3.3 (VIN)
/piezo: C1.1, J6.1, TP3.1
GND: C2.2, C3.2, C4.2, C5.2, C6.2, C8.2, C10.2, C11.1, C12.1, C19.2, C22.2, C23.2, C25.2, C28.1, C29.1, J1.1, J2.1, J4.1, J5.1, J6.2, J7.2, J8.5 (GND), J8.SH1 (SHIELD), J8.SH2 (SHIELD__1), J8.SH3 (SHIELD__2), J8.SH4 (SHIELD__3), J8.SH5 (SHIELD__4), J8.SH6 (SHIELD__5), R4.1, R7.2, R12.2, R13.2, R15.2, S1.3 (COM_2), S2.3 (COM_2), TP17.1, TP18.1, TP19.1, U1.2 (-INPUT), U1.4 (GND), U2.1 (GND), U3.1 (GND), U5.1 (GND), U5.40 (GND), U5.41 (GND)
unnamed: C13.1, R10.2
unnamed: J4.2, R2.1
unnamed: J5.2, R3.1
unnamed: C1.2, R4.2, U1.3 (+INPUT)
unnamed: R10.1, U1.1 (GAIN)
unnamed: C13.2, U1.8 (GAIN__1)
unnamed: R6.2, R7.1, R9.1, TP4.1, U1.5 (VOUT)
unnamed: C7.1, U2.6 (BST)
unnamed: R11.2, R12.1, U2.4 (FB)
unnamed: C7.2, L1.1, U2.2 (SW)
unnamed: C9.1, U3.6 (BST)
unnamed: R5.2, R13.1, U3.4 (FB)
unnamed: C9.2, L2.1, U3.2 (SW)

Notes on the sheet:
Power Subsystem
Audio/Vibration Subsystem
Microcontroller Subsystem
UI/LCD Subsystem
Motor Subsystem

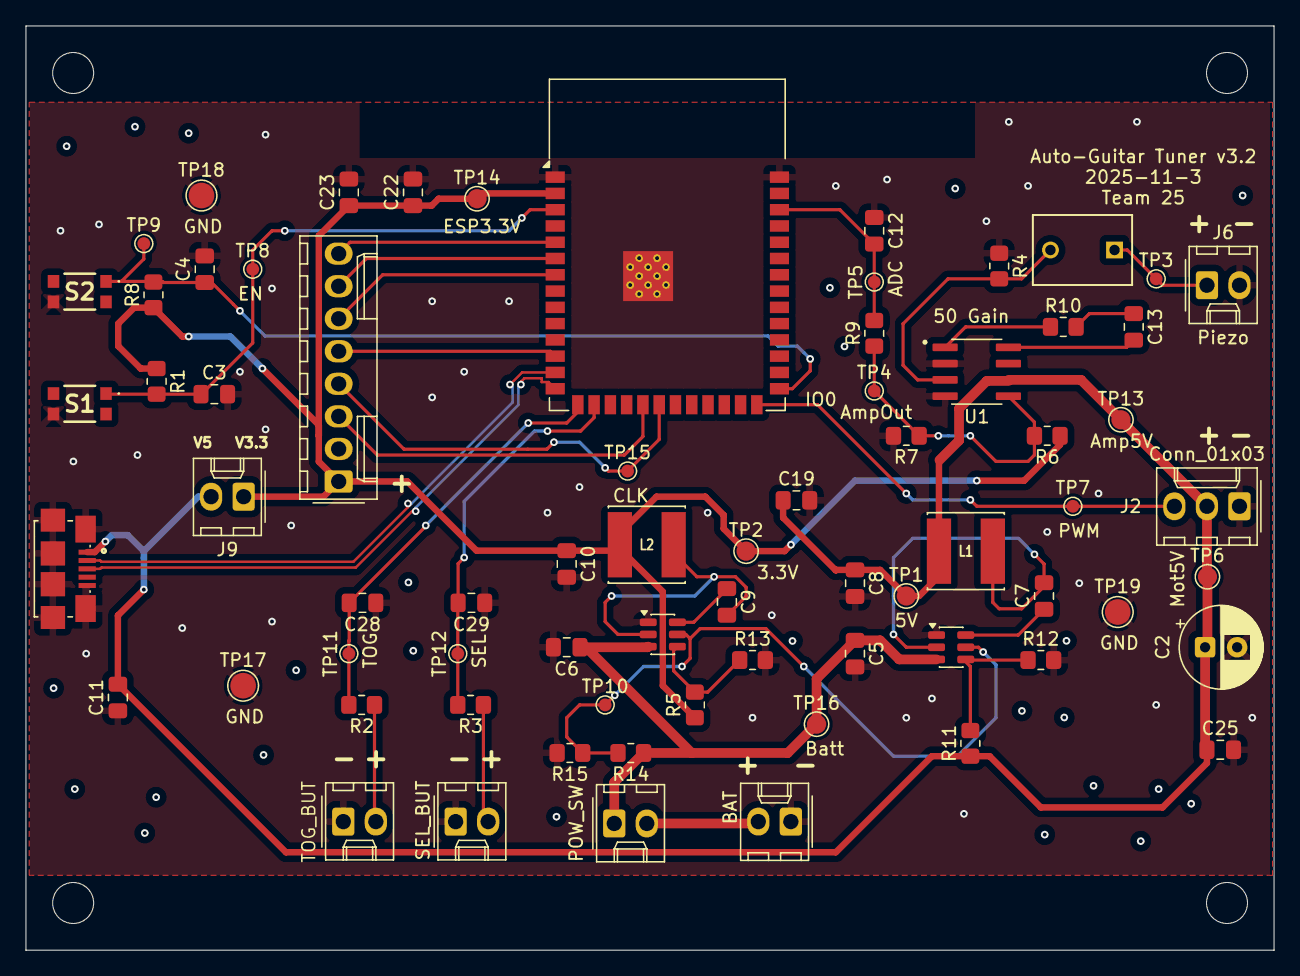
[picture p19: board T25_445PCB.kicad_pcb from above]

Board: 2 copper layers, 97.4 x 72.1 mm, 74 parts (0 on the bottom side), 34 nets.

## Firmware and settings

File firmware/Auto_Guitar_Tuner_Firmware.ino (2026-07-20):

#include <Adafruit_GFX.h>
#include <Adafruit_ST7789.h>
#include <SPI.h>
#include <arduinoFFT.h>
#include <ESP32Servo.h>

// ===== TFT DISPLAY (PCB PINOUT - ST7789 Waveshare 2.4") =====
#define TFT_MOSI  11
#define TFT_CLK   12
#define TFT_CS    8
#define TFT_DC    7
#define TFT_RST   6
#define TFT_BL    10

Adafruit_ST7789 tft = Adafruit_ST7789(TFT_CS, TFT_DC, TFT_RST);

// ===== BUTTONS (PCB PINOUT) - ACTIVE HIGH =====
#define BTN_TOGGLE    46
#define BTN_SELECT    3

// Button state tracking (active HIGH: pressed=HIGH, released=LOW)
bool lastButtonState[2] = {LOW, LOW};
unsigned long buttonPressStart[2] = {0, 0};
bool buttonLongPressTriggered[2] = {false, false};

// ===== PIEZO SENSOR (PCB PINOUT) =====
const int PIEZO_PIN = 2;

// ===== SERVO MOTOR (PCB PINOUT) =====
const int SERVO_PIN = 45;

// ===== FFT Configuration =====
const uint16_t SAMPLES = 4096;
const double SAMPLING_FREQ = 8192;
ArduinoFFT<double> FFT = ArduinoFFT<double>();
double *vReal;
double *vImag;

// ===== STABLE PITCH TRACKING =====
const int FREQ_STABLE_WINDOW = 5;          // how many frames must agree
const float FREQ_STABLE_CENTS = 6.0f;      // max spread within window
const float SIGNAL_START_THRESHOLD = 10.0; // when we start tracking a pluck
const float SIGNAL_END_THRESHOLD   = 4.0;  // when we consider pluck finished
const unsigned long HOLD_AFTER_SILENCE = 400; // ms to keep last pitch

float candidateFreqs[FREQ_STABLE_WINDOW] = {0};
int candidateIdx = 0;
bool haveStableFreq = false;
float stableFreq = 0.0f;
unsigned long lastLoudTime = 0;


// ===== SYSTEM STATES =====
enum SystemState {
  STATE_OFF,
  STATE_STANDBY,
  STATE_TUNING,
  STATE_AUTO_TUNE_ALL,
  STATE_STRING_SELECT,
  STATE_MODE_SELECT,
  STATE_STATISTICS,
  STATE_SETTINGS
};

enum TuningMode {
  MODE_STANDARD,
  MODE_HALF_STEP_DOWN,
  MODE_HALF_STEP_UP,
  MODE_FULL_STEP_DOWN
};

SystemState currentState = STATE_STANDBY;
TuningMode tuningMode = MODE_STANDARD;
int selectedString = -1;
bool isAutoMode = true;

// ===== AUTO TUNE ALL =====
int autoTuneCurrentString = 0;
bool autoTuneInProgress = false;
unsigned long autoTuneStringStartTime = 0;
const unsigned long AUTO_TUNE_TIMEOUT = 30000;

// ===== TUNING DEFINITIONS =====
struct TuningDef {
  const char* name;
  float freqs[6];
};

TuningDef tuningModes[] = {
  {"STANDARD", {82.41, 110.0, 146.83, 196.0, 246.94, 329.63}},
  {"Eb Standard", {77.78, 103.83, 138.59, 185.0, 233.08, 311.13}},
  {"DADGAD", {73.42, 110.10, 146.83, 196.00, 220.0, 293.66}},
  {"Open G", {73.42, 98.0, 146.83, 196.00, 246.94, 293.66}}
};

const char* STRING_NAMES[] = {"E2", "A2", "D3", "G3", "B3", "E4"};

// Analysis settings
const float F_MIN = 70.0f;
const float F_MAX = 350.0f;
const float NOISE_THRESHOLD = 12.0;
int TUNE_TOLERANCE = 5;

// Smoothing
const int SMOOTH_WINDOW = 3;
float freqHistory[SMOOTH_WINDOW] = {0};
int histIdx = 0;

const char* NOTE_NAMES[] = {"C","C#","D","D#","E","F","F#","G","G#","A","A#","B"};

// Signal meter
float signalLevel = 0;

// ===== HISTORY GRAPH =====
const int HISTORY_SIZE = 40;
float freqHistoryGraph[HISTORY_SIZE] = {0};
int historyGraphIdx = 0;

unsigned long lastReadTime = 0;
const unsigned long READ_INTERVAL = 3000;

// ===== STATISTICS =====
struct Statistics {
  int totalStringsTuned;
  int sessionStringsTuned;
  unsigned long totalTuningTime;
  unsigned long sessionStartTime;
  int successfulTunes;
  int failedTunes;
  float avgTuningTime;
} stats = {0, 0, 0, 0, 0, 0, 0.0};

unsigned long currentTuneStartTime = 0;

// ===== SERVO =====
Servo tunerServo;
int servoPos = 90;
int targetServoPos = 90;
unsigned long lastServoMove = 0;
uint32_t SERVO_MOVE_PERIOD = 150;
bool servoAttached = false;

int TUNE_STABLE_COUNT = 5;
int stableCount = 0;
int lastCents = 0;

bool servoIsMoving = false;
unsigned long servoMoveStartTime = 0;
const uint32_t SERVO_MOVE_DURATION = 120;

// ===== ANIMATION =====
int animationFrame = 0;
unsigned long lastAnimationTime = 0;
bool showSuccessAnimation = false;
int successAnimationFrame = 0;
unsigned long successAnimationStartTime = 0;
const unsigned long SUCCESS_DISPLAY_TIME = 3000;

// ===== BATTERY SIMULATION =====
int batteryLevel = 100;

// ===== COLOR SCHEME =====
#define COLOR_BG        0x0841
#define COLOR_CARD      0x1082
#define COLOR_PRIMARY   0x07FF
#define COLOR_SUCCESS   0x07E0
#define COLOR_WARNING   0xFD20
#define COLOR_DANGER    0xF800
#define COLOR_TEXT      0xFFFF
#define COLOR_TEXT_DIM  0x7BEF
#define COLOR_ACCENT    0x07FF
#define COLOR_PURPLE    0x781F
#define COLOR_GOLD      0xFEA0

// ===== PIEZO CALIBRATION =====
float PIEZO_GAIN_ADJUST = 1.5;
bool USE_DC_BLOCK = true;

// ===== UI HELPER FUNCTIONS =====

void drawCard(int x, int y, int w, int h, uint16_t color = COLOR_CARD) {
  tft.fillRoundRect(x, y, w, h, 8, color);
}

void drawProgressBar(int x, int y, int w, int h, int value, int maxValue, uint16_t color) {
  tft.drawRoundRect(x, y, w, h, 4, COLOR_TEXT_DIM);
  int fillWidth = map(constrain(value, 0, maxValue), 0, maxValue, 0, w - 4);
  if (fillWidth > 0) {
    tft.fillRoundRect(x + 2, y + 2, fillWidth, h - 4, 2, color);
  }
}



void drawCentsMeter(int x, int y, int w, int h, int cents) {
  tft.fillRoundRect(x, y, w, h, 6, COLOR_CARD);
  
  int centerX = x + w/2;
  tft.drawFastVLine(centerX, y + 5, h - 10, COLOR_TEXT_DIM);
  
  int tolerancePixels = map(TUNE_TOLERANCE, 0, 50, 0, w/2);
  tft.drawFastVLine(centerX - tolerancePixels, y + 5, h - 10, COLOR_SUCCESS);
  tft.drawFastVLine(centerX + tolerancePixels, y + 5, h - 10, COLOR_SUCCESS);
  
  int c = constrain(cents, -50, 50);
  int indicatorX;
  if (c < 0) {
    indicatorX = centerX + map(c, -50, 0, -w/2 + 8, 0);
  } else {
    indicatorX = centerX + map(c, 0, 50, 0, w/2 - 8);
  }
  
  uint16_t color = COLOR_SUCCESS;
  if (abs(cents) > TUNE_TOLERANCE && abs(cents) <= 15) color = COLOR_WARNING;
  else if (abs(cents) > 15) color = COLOR_DANGER;
  
  tft.fillCircle(indicatorX, y + h/2, 8, color);
  tft.drawCircle(indicatorX, y + h/2, 9, COLOR_TEXT);
}

void drawBatteryIcon(int x, int y) {
  tft.drawRect(x, y + 2, 20, 10, COLOR_TEXT_DIM);
  tft.fillRect(x + 20, y + 4, 2, 6, COLOR_TEXT_DIM);
  
  uint16_t fillColor = COLOR_SUCCESS;
  if (batteryLevel < 20) fillColor = COLOR_DANGER;
  else if (batteryLevel < 50) fillColor = COLOR_WARNING;
  
  int fillWidth = map(batteryLevel, 0, 100, 0, 16);
  if (fillWidth > 0) {
    tft.fillRect(x + 2, y + 4, fillWidth, 6, fillColor);
  }
  
  tft.setTextSize(1);
  tft.setTextColor(COLOR_TEXT_DIM);
  tft.setCursor(x + 24, y + 3);
  tft.print(batteryLevel);
  tft.print("%");
}

void drawFrequencyGraph(int x, int y, int w, int h, float targetFreq) {
  tft.fillRect(x, y, w, h, COLOR_BG);
  tft.drawRect(x, y, w, h, COLOR_TEXT_DIM);
  
  int targetY = y + h/2;
  tft.drawFastHLine(x, targetY, w, COLOR_SUCCESS);
  
  for (int i = 1; i < HISTORY_SIZE; i++) {
    int idx1 = (historyGraphIdx + i - 1) % HISTORY_SIZE;
    int idx2 = (historyGraphIdx + i) % HISTORY_SIZE;
    
    if (freqHistoryGraph[idx1] > 0 && freqHistoryGraph[idx2] > 0) {
      float cents1 = 1200.0f * log2f(freqHistoryGraph[idx1] / targetFreq);
      float cents2 = 1200.0f * log2f(freqHistoryGraph[idx2] / targetFreq);
      
      int y1 = targetY - map(constrain(cents1, -50, 50), -50, 50, -h/2 + 2, h/2 - 2);
      int y2 = targetY - map(constrain(cents2, -50, 50), -50, 50, -h/2 + 2, h/2 - 2);
      
      int x1 = x + map(i - 1, 0, HISTORY_SIZE - 1, 0, w);
      int x2 = x + map(i, 0, HISTORY_SIZE - 1, 0, w);
      
      tft.drawLine(x1, y1, x2, y2, COLOR_ACCENT);
    }
  }
}

void addToFrequencyHistory(float freq) {
  freqHistoryGraph[historyGraphIdx] = freq;
  historyGraphIdx = (historyGraphIdx + 1) % HISTORY_SIZE;
}

void drawSuccessAnimation() {
  if (!showSuccessAnimation) return;
  
  int centerX = 160;
  int centerY = 120;
  int size = 30 + (successAnimationFrame % 10);
  
  tft.fillCircle(centerX, centerY, size, COLOR_SUCCESS);
  
  tft.drawLine(centerX - 10, centerY, centerX - 3, centerY + 10, COLOR_TEXT);
  tft.drawLine(centerX - 3, centerY + 10, centerX + 12, centerY - 10, COLOR_TEXT);
  tft.drawLine(centerX - 9, centerY, centerX - 3, centerY + 9, COLOR_TEXT);
  tft.drawLine(centerX - 3, centerY + 9, centerX + 11, centerY - 10, COLOR_TEXT);
  
  for (int i = 0; i < 4; i++) {
    int angle = (successAnimationFrame * 10 + i * 90) % 360;
    int sx = centerX + cos(angle * PI / 180) * (40 + successAnimationFrame);
    int sy = centerY + sin(angle * PI / 180) * (40 + successAnimationFrame);
    tft.fillCircle(sx, sy, 3, COLOR_GOLD);
  }
  
  successAnimationFrame++;
  if (successAnimationFrame > 60) {
    successAnimationFrame = 0;
  }
}

// ===== UI SCREENS =====

void drawStandbyScreen() {
  tft.fillScreen(COLOR_BG);
  
  drawBatteryIcon(250, 5);
  
  drawCard(10, 10, 300, 60);
  tft.setTextSize(3);
  tft.setTextColor(COLOR_PRIMARY);
  tft.setCursor(50, 25);
  tft.print("GUITAR TUNER");
  
  drawCard(10, 80, 300, 50);
  tft.setTextSize(2);
  tft.setTextColor(COLOR_TEXT_DIM);
  tft.setCursor(20, 88);
  tft.print("Status:");
  tft.setTextSize(2);
  tft.setTextColor(COLOR_WARNING);
  tft.setCursor(110, 88);
  tft.print("READY");
  
  tft.setTextSize(1);
  tft.setTextColor(COLOR_ACCENT);
  tft.setCursor(20, 108);
  tft.print("Session: ");
  tft.print(stats.sessionStringsTuned);
  tft.print(" strings");
  
  drawCard(10, 140, 145, 38);
  tft.setTextSize(1);
  tft.setTextColor(COLOR_TEXT_DIM);
  tft.setCursor(20, 148);
  tft.print("MODE");
  tft.setTextSize(1);
  tft.setTextColor(COLOR_ACCENT);
  tft.setCursor(20, 160);
  tft.print(tuningModes[tuningMode].name);
  
  drawCard(165, 140, 145, 38);
  tft.setTextSize(1);
  tft.setTextColor(COLOR_TEXT_DIM);
  tft.setCursor(175, 148);
  tft.print("STRING");
  tft.setTextSize(1);
  tft.setTextColor(COLOR_ACCENT);
  tft.setCursor(175, 160);
  if (isAutoMode) tft.print("AUTO");
  else tft.print(STRING_NAMES[selectedString]);
  
  drawCard(10, 188, 300, 40);
  tft.setTextSize(1);
  tft.setTextColor(COLOR_TEXT_DIM);
  tft.setCursor(20, 195);
  tft.print("TOGGLE: Start  |  SELECT: String/Mode");
  tft.setTextSize(1);
  tft.setTextColor(COLOR_PURPLE);
  tft.setCursor(20, 210);
  tft.print("Long TOGGLE: Auto All | Long SELECT: Mode");
}

void drawTuningScreen() {
  tft.fillScreen(COLOR_BG);
  
  drawBatteryIcon(250, 5);
  
  drawCard(10, 5, 230, 30);
  tft.setTextSize(2);
  tft.setTextColor(COLOR_SUCCESS);
  tft.setCursor(20, 12);
  tft.print("TUNING");
  
  tft.setTextSize(1);
  tft.setTextColor(COLOR_TEXT_DIM);
  tft.setCursor(150, 12);
  tft.print(tuningModes[tuningMode].name);
  
  drawCard(10, 40, 300, 28);
  tft.setTextSize(1);
  tft.setTextColor(COLOR_TEXT_DIM);
  tft.setCursor(20, 47);
  tft.print("SIGNAL");
  
  drawCard(10, 73, 145, 40);
  tft.setTextSize(1);
  tft.setTextColor(COLOR_TEXT_DIM);
  tft.setCursor(20, 80);
  tft.print("FREQUENCY");
  
  drawCard(165, 73, 145, 40);
  tft.setTextSize(1);
  tft.setTextColor(COLOR_TEXT_DIM);
  tft.setCursor(175, 80);
  tft.print("NOTE");
  
  tft.setTextSize(1);
  tft.setTextColor(COLOR_TEXT_DIM);
  tft.setCursor(20, 118);
  tft.print("TUNING PROGRESS");
  
  tft.setTextSize(1);
  tft.setTextColor(COLOR_TEXT_DIM);
  tft.setCursor(20, 173);
  tft.print("ACCURACY");
}

void drawAutoTuneAllScreen() {
  tft.fillScreen(COLOR_BG);
  
  drawBatteryIcon(250, 5);
  
  drawCard(10, 10, 300, 45);
  tft.setTextSize(3);
  tft.setTextColor(COLOR_PURPLE);
  tft.setCursor(30, 20);
  tft.print("AUTO TUNE");
  
  drawCard(10, 65, 300, 60);
  tft.setTextSize(2);
  tft.setTextColor(COLOR_TEXT);
  tft.setCursor(20, 75);
  tft.print("Progress:");
  
  int yStart = 95;
  for (int i = 0; i < 6; i++) {
    int x = 20 + (i % 3) * 95;
    int y = yStart + (i / 3) * 25;
    
    uint16_t color = COLOR_TEXT_DIM;
    if (i < autoTuneCurrentString) color = COLOR_SUCCESS;
    else if (i == autoTuneCurrentString) color = COLOR_WARNING;
    
    tft.setTextSize(2);
    tft.setTextColor(color);
    tft.setCursor(x, y);
    tft.print(STRING_NAMES[i]);
    
    if (i < autoTuneCurrentString) {
      tft.print(" ");
      tft.setTextColor(COLOR_SUCCESS);
      tft.print((char)251);
    } else if (i == autoTuneCurrentString) {
      tft.print(" ...");
    }
  }
  
  tft.setTextSize(1);
  tft.setTextColor(COLOR_TEXT_DIM);
  tft.setCursor(20, 150);
  tft.print("Overall Progress:");
  drawProgressBar(20, 163, 280, 20, autoTuneCurrentString, 6, COLOR_PURPLE);
  
  if (autoTuneCurrentString < 6) {
    drawCard(10, 190, 300, 45);
    tft.setTextSize(1);
    tft.setTextColor(COLOR_TEXT_DIM);
    tft.setCursor(20, 198);
    tft.print("Current: ");
    tft.setTextSize(2);
    tft.setTextColor(COLOR_WARNING);
    tft.print(STRING_NAMES[autoTuneCurrentString]);
    tft.print(" (");
    tft.print((int)tuningModes[tuningMode].freqs[autoTuneCurrentString]);
    tft.print(" Hz)");
  }
}

void updateAutoTuneAllScreen(float freq, int cents) {
  tft.fillRect(20, 213, 280, 20, COLOR_CARD);
  tft.setTextSize(1);
  tft.setTextColor(COLOR_ACCENT);
  tft.setCursor(20, 215);
  
  if (freq > 0) {
    tft.print("Detected: ");
    tft.print((int)freq);
    tft.print(" Hz (");
    if (cents > 0) tft.print("+");
    tft.print(cents);
    tft.print(" cents)");
  } else {
    tft.print("Waiting for signal...");
  }
}

void drawStringSelectScreen() {
  tft.fillScreen(COLOR_BG);
  
  drawBatteryIcon(250, 5);
  
  drawCard(10, 5, 300, 35);
  tft.setTextSize(2);
  tft.setTextColor(COLOR_PRIMARY);
  tft.setCursor(30, 12);
  tft.print("SELECT STRING");
  
  bool autoSelected = isAutoMode;
  drawCard(10, 45, 145, 38);
  tft.setTextSize(2);
  tft.setTextColor(autoSelected ? COLOR_SUCCESS : COLOR_TEXT);
  tft.setCursor(40, 55);
  tft.print("AUTO");
  if (autoSelected) {
    tft.drawRoundRect(10, 45, 145, 38, 8, COLOR_SUCCESS);
    tft.drawRoundRect(11, 46, 143, 36, 7, COLOR_SUCCESS);
  }
  
  tft.setTextSize(1);
  tft.setTextColor(COLOR_ACCENT);
  tft.setCursor(165, 50);
  tft.print("Selected:");
  tft.setTextSize(2);
  tft.setCursor(165, 62);
  if (isAutoMode) {
    tft.print("AUTO");
  } else {
    tft.print(STRING_NAMES[selectedString]);
  }
  
  for (int i = 0; i < 6; i++) {
    int col = i % 2;
    int row = i / 2;
    int x = 10 + col * 155;
    int y = 90 + row * 48;
    
    bool selected = (!isAutoMode && selectedString == i);
    drawCard(x, y, 145, 42);
    
    tft.setTextSize(2);
    tft.setTextColor(selected ? COLOR_SUCCESS : COLOR_TEXT);
    tft.setCursor(x + 10, y + 8);
    tft.print(STRING_NAMES[i]);
    
    tft.setTextSize(1);
    tft.setTextColor(COLOR_TEXT_DIM);
    tft.setCursor(x + 10, y + 28);
    tft.print((int)tuningModes[tuningMode].freqs[i]);
    tft.print("Hz");
    
    if (selected) {
      tft.drawRoundRect(x, y, 145, 42, 8, COLOR_SUCCESS);
      tft.drawRoundRect(x + 1, y + 1, 143, 40, 7, COLOR_SUCCESS);
    }
  }
  
  tft.setTextSize(1);
  tft.setTextColor(COLOR_TEXT_DIM);
  tft.setCursor(20, 228);
  tft.print("SELECT to cycle | TOGGLE to confirm");
}

void drawModeSelectScreen() {
  tft.fillScreen(COLOR_BG);
  
  drawBatteryIcon(250, 5);
  
  drawCard(10, 10, 300, 50);
  tft.setTextSize(2);
  tft.setTextColor(COLOR_PRIMARY);
  tft.setCursor(20, 22);
  tft.print("TUNING MODE");
  
  for (int i = 0; i < 4; i++) {
    int y = 70 + i * 42;
    bool selected = (tuningMode == i);
    
    drawCard(10, y, 300, 38);
    
    tft.setTextSize(2);
    tft.setTextColor(selected ? COLOR_SUCCESS : COLOR_TEXT);
    tft.setCursor(20, y + 10);
    tft.print(tuningModes[i].name);
    
    if (selected) {
      tft.drawRoundRect(10, y, 300, 38, 8, COLOR_SUCCESS);
      tft.drawRoundRect(11, y + 1, 298, 36, 7, COLOR_SUCCESS);
    }
  }
  
  tft.setTextSize(1);
  tft.setTextColor(COLOR_TEXT_DIM);
  tft.setCursor(20, 228);
  tft.print("SELECT to cycle | TOGGLE to confirm");
}

void drawStatisticsScreen() {
  tft.fillScreen(COLOR_BG);
  
  drawBatteryIcon(250, 5);
  
  drawCard(10, 10, 300, 50);
  tft.setTextSize(3);
  tft.setTextColor(COLOR_GOLD);
  tft.setCursor(40, 22);
  tft.print("STATISTICS");
  
  drawCard(10, 70, 145, 75);
  tft.setTextSize(1);
  tft.setTextColor(COLOR_TEXT_DIM);
  tft.setCursor(20, 78);
  tft.print("SESSION");
  tft.setTextSize(3);
  tft.setTextColor(COLOR_SUCCESS);
  tft.setCursor(35, 100);
  tft.print(stats.sessionStringsTuned);
  tft.setTextSize(1);
  tft.setTextColor(COLOR_TEXT_DIM);
  tft.setCursor(20, 130);
  tft.print("Strings Tuned");
  
  drawCard(165, 70, 145, 75);
  tft.setTextSize(1);
  tft.setTextColor(COLOR_TEXT_DIM);
  tft.setCursor(175, 78);
  tft.print("LIFETIME");
  tft.setTextSize(3);
  tft.setTextColor(COLOR_PRIMARY);
  tft.setCursor(190, 100);
  tft.print(stats.totalStringsTuned);
  tft.setTextSize(1);
  tft.setTextColor(COLOR_TEXT_DIM);
  tft.setCursor(175, 130);
  tft.print("Total Tuned");
  
  drawCard(10, 155, 145, 60);
  tft.setTextSize(1);
  tft.setTextColor(COLOR_TEXT_DIM);
  tft.setCursor(20, 163);
  tft.print("SUCCESS RATE");
  
  int total = stats.successfulTunes + stats.failedTunes;
  int successRate = total > 0 ? (stats.successfulTunes * 100) / total : 100;
  tft.setTextSize(3);
  tft.setTextColor(COLOR_SUCCESS);
  tft.setCursor(40, 180);
  tft.print(successRate);
  tft.print("%");
  
  drawCard(165, 155, 145, 60);
  tft.setTextSize(1);
  tft.setTextColor(COLOR_TEXT_DIM);
  tft.setCursor(175, 163);
  tft.print("AVG TIME");
  tft.setTextSize(2);
  tft.setTextColor(COLOR_WARNING);
  tft.setCursor(180, 185);
  tft.print(stats.avgTuningTime, 1);
  tft.print("s");
  
  tft.setTextSize(1);
  tft.setTextColor(COLOR_TEXT_DIM);
  tft.setCursor(50, 225);
  tft.print("Press any button to return");
}

void drawSettingsScreen() {
  tft.fillScreen(COLOR_BG);
  
  drawBatteryIcon(250, 5);
  
  drawCard(10, 10, 300, 45);
  tft.setTextSize(3);
  tft.setTextColor(COLOR_ACCENT);
  tft.setCursor(60, 20);
  tft.print("SETTINGS");
  
  drawCard(10, 65, 300, 40);
  tft.setTextSize(1);
  tft.setTextColor(COLOR_TEXT_DIM);
  tft.setCursor(20, 73);
  tft.print("Tune Tolerance:");
  tft.setTextSize(2);
  tft.setTextColor(COLOR_SUCCESS);
  tft.setCursor(20, 88);
  tft.print("+/- ");
  tft.print(TUNE_TOLERANCE);
  tft.print(" cents");
  
  drawCard(10, 115, 300, 40);
  tft.setTextSize(1);
  tft.setTextColor(COLOR_TEXT_DIM);
  tft.setCursor(20, 123);
  tft.print("Servo Speed:");
  tft.setTextSize(2);
  tft.setTextColor(COLOR_WARNING);
  tft.setCursor(20, 138);
  tft.print(SERVO_MOVE_PERIOD);
  tft.print(" ms");
  
  drawCard(10, 165, 300, 40);
  tft.setTextSize(1);
  tft.setTextColor(COLOR_TEXT_DIM);
  tft.setCursor(20, 173);
  tft.print("Stability Count:");
  tft.setTextSize(2);
  tft.setTextColor(COLOR_PRIMARY);
  tft.setCursor(20, 188);
  tft.print(TUNE_STABLE_COUNT);
  tft.print(" samples");
  
  tft.setTextSize(1);
  tft.setTextColor(COLOR_TEXT_DIM);
  tft.setCursor(30, 220);
  tft.print("Long press SELECT to adjust");
}
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
void loop() {
  readSinglePiezoValue();
  handleButtons();
  
  static unsigned long lastBatteryUpdate = 0;
  if (millis() - lastBatteryUpdate > 60000) {
    if (batteryLevel > 0) batteryLevel--;
    lastBatteryUpdate = millis();
  }
  
  if (currentState == STATE_TUNING || currentState == STATE_AUTO_TUNE_ALL) {
    attachServoIfNeeded();
    
    checkSuccessAnimationComplete();
    
    if (!showSuccessAnimation) {
      captureSamples();
      preprocessSignal();

    //   float freq = 0.0f;
    //   String note = "--";
    //   int cents = 0;

    //   if (signalLevel > 5.0f) {
    //     float raw = findPeakFrequency();
    //     freq = smoothFreq(raw);
    //     freqToNote(freq, note, cents);
        
    //     int stringNum = identifyString(freq);
    //     if (stringNum >= 0 && freq > 0) {
    //       updateServoFromCents(cents);
    //     }
    //   }

      float freq = 0.0f;
      String note = "--";
      int cents = 0;

      // Only try to extract a new candidate freq when the signal is loud enough
      float candidate = 0.0f;
      if (signalLevel > SIGNAL_START_THRESHOLD) {
        float raw = findPeakFrequency();
        candidate = smoothFreq(raw);   // optional extra smoothing
      }

      // Let the stable-frequency tracker decide what pitch to use
      freq = updateStableFrequency(candidate);

      if (freq > 0.0f) {
        freqToNote(freq, note, cents);

        int stringNum = identifyString(freq);
        if (stringNum >= 0) {
          updateServoFromCents(cents);
        }
      } else {
        note = "--";
        cents = 0;
      }


      if (currentState == STATE_TUNING) {
        updateTuningScreen(freq, note, cents);
      } else if (currentState == STATE_AUTO_TUNE_ALL) {
        updateAutoTuneAllScreen(freq, cents);
      }
    }
    
    if (showSuccessAnimation) {
      drawSuccessAnimation();
    }
    
    delay(20);
    yield();
  } else {
    detachServoIfNeeded();
    delay(20);
    yield();
  }
}
